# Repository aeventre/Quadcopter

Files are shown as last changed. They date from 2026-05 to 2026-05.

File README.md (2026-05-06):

# DIY Quadcopter

A from-scratch DIY quadcopter with a custom-designed flight computer PCB and custom frame CAD. Everything except the ESC and radio module was built from the ground up.
drone

## Overview

This repository contains the KiCad hardware design files for the custom flight controller PCB and the Arduino/PlatformIO firmware that runs on it. The flight controller interfaces a four channel off-the-shelf ESC, an RC receiver via CRSF/ExpressLRS, and an onboard 6-axis IMU to stabilize and control the drone.

## Hardware

### Flight Controller (Custom PCB)

| Component | Part | Role |
|---|---|---|
| MCU | Raspberry Pi Pico (RP2040 / RP2350) | Main processor |
| IMU | LSM6DSO32TR | 6-axis accelerometer + gyroscope (SPI) |
| Power regulator | TPS563200 | 3A synchronous step-down, 4.5–17V in → 3.3V |
| Motor switching | AO3400A MOSFET | N-channel switching |
| Level shifting | BSS138 MOSFET | 3.3V ↔ 5V logic |
| Transient protection | SMAJ14A TVS diode | Input voltage spike protection |

### Interfaces
- **4× ESC connectors** (Motor 1–4) — off-the-shelf 4 channel ESC
- **RC receiver connector** — CRSF/ExpressLRS
- **Electromagnet connector** — payload drop mechanism
- **SPI** — IMU (LSM6DSO32TR on SPI1)
- **USB** — programming and debug via Pico's onboard USB

### Frame & CAD
Custom-designed from scratch (CAD files not included in this repo).

## Firmware

Built with [PlatformIO](https://platformio.org/) targeting the Raspberry Pi Pico using the [earlephilhower Arduino core](https://github.com/earlephilhower/arduino-pico).

### Flight Controller (`Code/Controller_Code/`)

The main flight firmware. Initializes the IMU, ESCs, and CRSF receiver, then runs the control loop.

**Libraries (`lib/`)**

| Library | Description |
|---|---|
| `DroneController` | Core flight controller — PID loop, flight modes, arm/disarm, RAM blackbox |
| `ImuLSM6` | SPI driver for the LSM6DSO32TR (gyro + accel reads) |
| `MotorLib` | PWM motor control via the Servo library (1000–2000 µs) |

**Flight modes**

- **Acro** — pure rate mode; stick input maps directly to roll/pitch/yaw rate setpoints fed into the inner PID loop
- **Balance** — self-leveling; an outer angle P+I loop computes rate setpoints from stick-commanded angles, which the inner rate PID tracks

**Control loop**

```
RC input (CRSF)
    │
    ├─ [Balance mode] Angle P+I → rate setpoint
    │
    └─ Rate PID (roll / pitch / yaw)
           │   gyro LP filter (α = 0.70)
           │   complementary filter for attitude (α = 0.98)
           ▼
       Motor mixer → 4× PWM ESC outputs
```

**RAM blackbox**

Up to 3000 samples are logged to RAM during flight (timestamp, RC inputs, rate commands, gyro rates, PID outputs, motor values, attitude angles). On disarm the log dumps over USB serial as CSV for offline analysis.

### Test Projects

| Project | Description |
|---|---|
| `Code/ELRS_Test/` | Standalone CRSF/ExpressLRS receiver test |
| `Code/ESC_Test/` | ESC test using DShot600 (bit-banged on Pico's second core at 2 kHz) |
| `Code/IMU_test/` | Standalone LSM6DSO32TR read/print test |

### Flight Analysis (`Code/Flight_Analysis/`)

MATLAB script (`PID_Analysis.m`) for post-flight analysis of blackbox CSV logs. Plots RC inputs, commanded vs. measured rates, rate errors, motor outputs, and estimated attitude. 103 flight logs are included.

## Repository Structure

```
Quadcopter/
├── Flight_Controller/
│   ├── Flight_Controller.kicad_pro
│   ├── Flight_Controller.kicad_sch
│   └── Flight_Controller.kicad_pcb
└── Code/
    ├── Controller_Code/          # Main flight firmware (PlatformIO)
    │   ├── src/main.cpp
    │   ├── lib/
    │   │   ├── DroneController/  # Flight controller, PID, blackbox
    │   │   ├── ImuLSM6/          # LSM6DSO32TR SPI driver
    │   │   └── MotorLib/         # PWM ESC control
    │   └── Tests/                # Component test sketches
    ├── ELRS_Test/                # ExpressLRS receiver test
    ├── ESC_Test/                 # DShot600 ESC test
    │   └── lib/DshotLib/         # DShot600 driver (dual-core)
    ├── IMU_test/                 # IMU read test
    └── Flight_Analysis/
        ├── PID_Analysis.m        # MATLAB blackbox analysis script
        └── flight_log_*.csv      # Captured flight logs (103 flights)
```

## Getting Started

### Hardware (KiCad)
1. Install [KiCad 7.x or later](https://www.kicad.org/download/)
2. Clone this repository:
   ```bash
   git clone https://github.com/alecv2211/Quadcopter.git
   ```
3. Open `Flight_Controller/Flight_Controller.kicad_pro`

### Firmware (PlatformIO)
1. Install [PlatformIO](https://platformio.org/install)
2. Open `Code/Controller_Code/` in VS Code with the PlatformIO extension
3. Connect the Pico via USB and run **Upload**

## License

Licensed under the [Apache License 2.0](LICENSE).

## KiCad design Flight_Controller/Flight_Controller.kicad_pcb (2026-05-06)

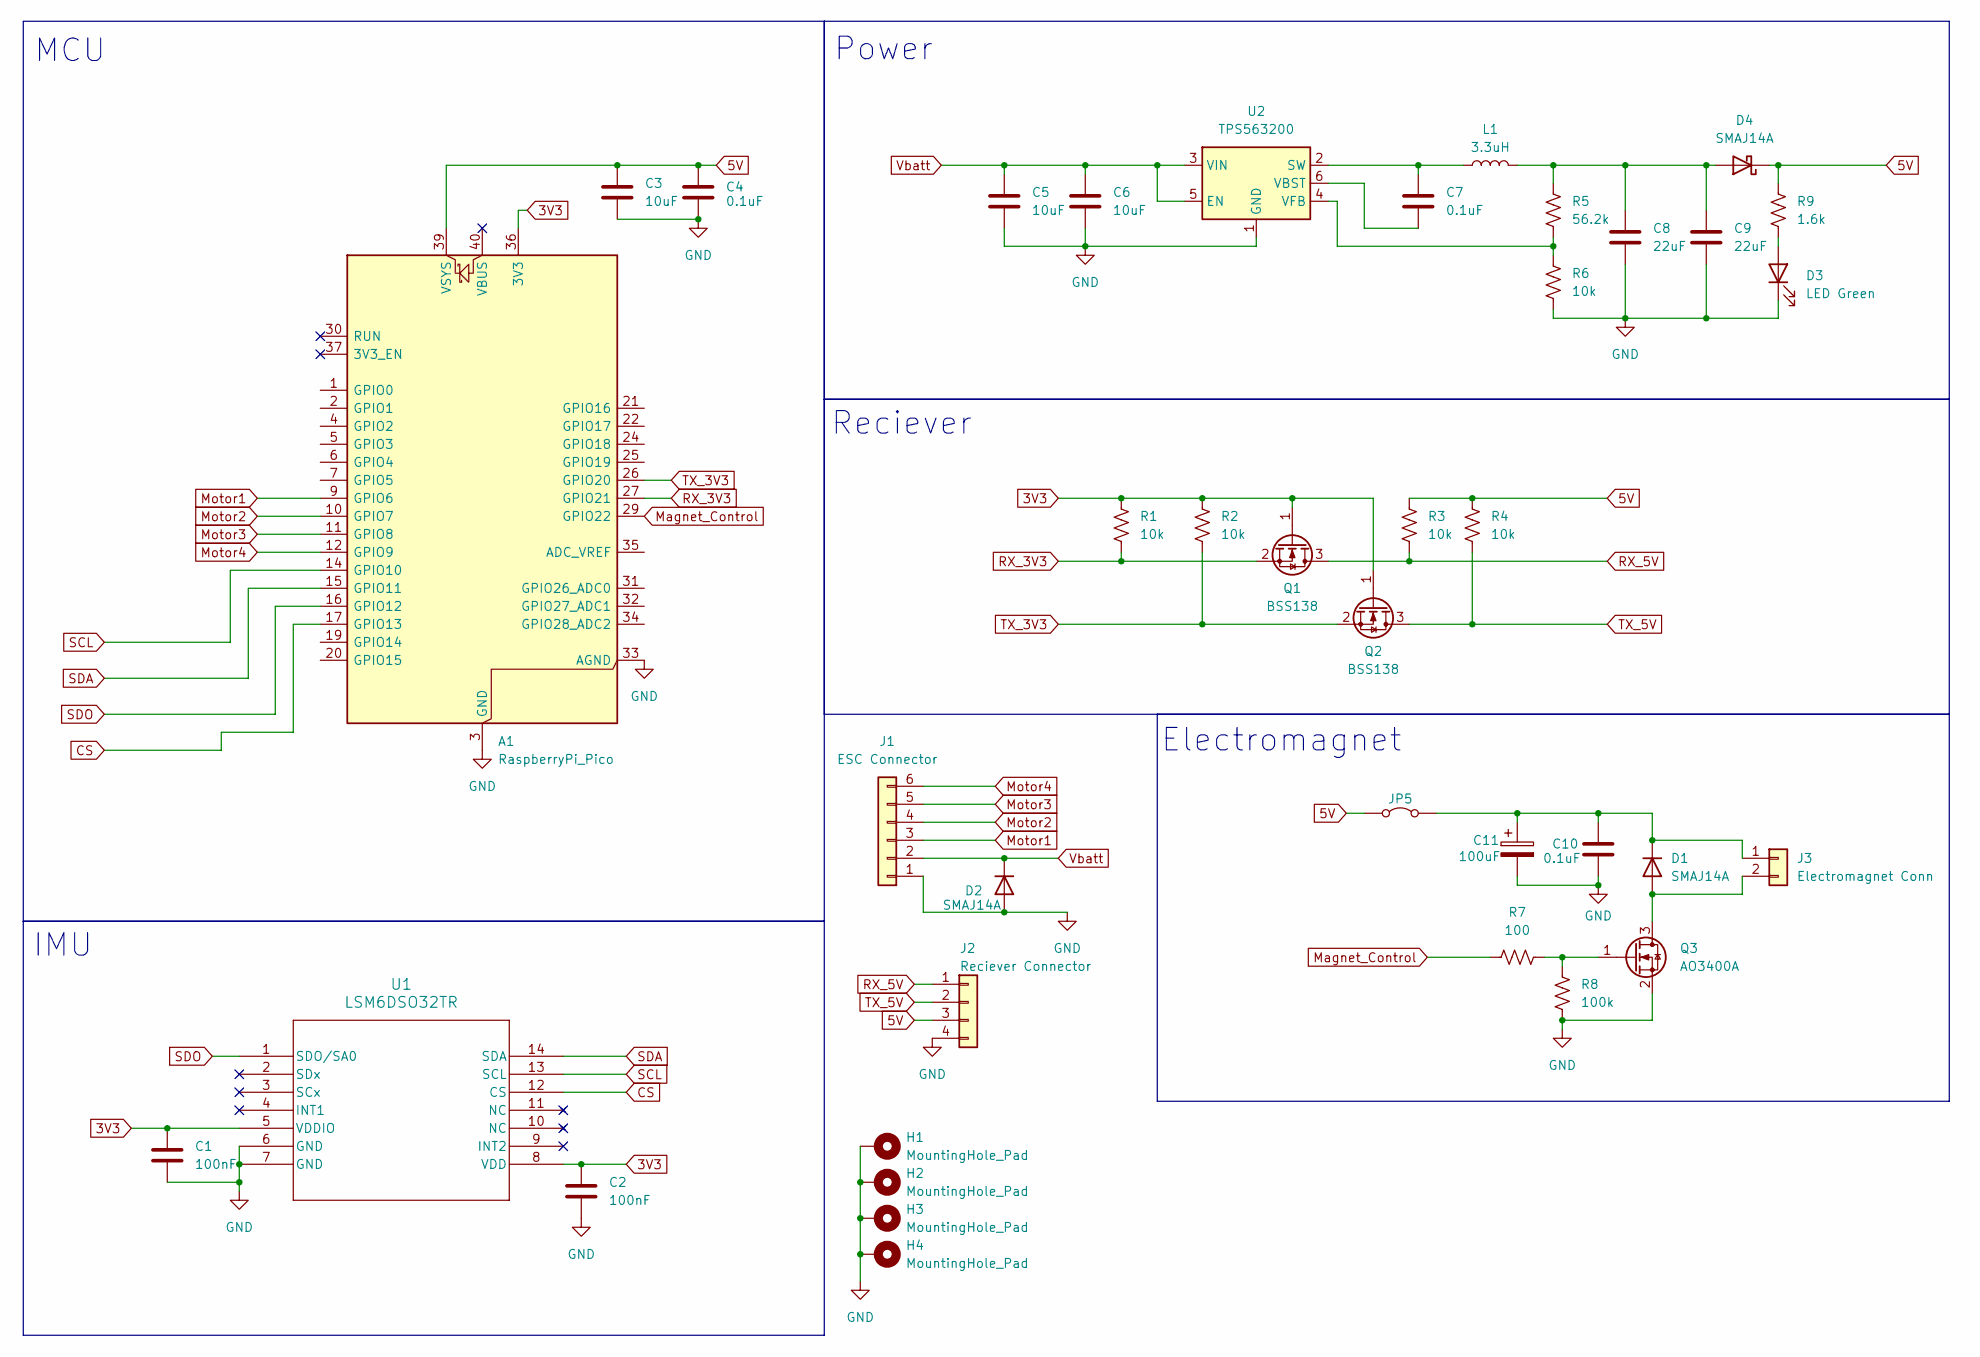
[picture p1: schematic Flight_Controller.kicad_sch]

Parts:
A1: RaspberryPi_Pico; RaspberryPi_Pico_Common_SMD
C1, C2: 100nF; C_0603_1608Metric_Pad1.08x0.95mm_HandSolder
C3: 10uF; C_0603_1608Metric_Pad1.08x0.95mm_HandSolder; Digikey Part Number 399-C0805C106K4PACTUCT-ND
C4: 0.1uF; C_0603_1608Metric_Pad1.08x0.95mm_HandSolder; Digikey Part Number 399-C0805C104M5UACTUCT-ND
C5, C6: 10uF; C_0603_1608Metric_Pad1.08x0.95mm_HandSolder
C7, C10: 0.1uF; C_0603_1608Metric_Pad1.08x0.95mm_HandSolder
C8, C9: 22uF; C_0603_1608Metric_Pad1.08x0.95mm_HandSolder
C11: 100uF; C_0603_1608Metric_Pad1.08x0.95mm_HandSolder
D1, D2, D4: SMAJ14A; D_SMA_Handsoldering
D3: LED Green; D_0603_1608Metric_Pad1.05x0.95mm_HandSolder
H1, H2, H3, H4: MountingHole_Pad; MountingHole_3.5mm_Pad
J1: ESC Connector; SolderWire-0.15sqmm_1x06_P4mm_D0.5mm_OD1.5mm_Relief
J2: Reciever Connector; Reciever_Module
J3: Electromagnet Conn; SolderWire-0.15sqmm_1x02_P4mm_D0.5mm_OD1.5mm_Relief
JP5: Jumper_2_Bridged; SolderJumper-2_P1.3mm_Open_TrianglePad1.0x1.5mm
L1: 3.3uH; L_Bourns-SRN8040_8x8.15mm
Q1, Q2: BSS138; SOT-23_Handsoldering
Q3: AO3400A; SOT-23
R1, R2, R3, R4: 10k; R_0603_1608Metric_Pad0.98x0.95mm_HandSolder; PART-NUMBER CPF0603F10KC1
R5: 56.2k; R_0603_1608Metric_Pad0.98x0.95mm_HandSolder
R6: 10k; R_0603_1608Metric_Pad0.98x0.95mm_HandSolder
R7: 100; R_0603_1608Metric_Pad0.98x0.95mm_HandSolder; PART-NUMBER CPF0603F10KC1
R8: 100k; R_0603_1608Metric_Pad0.98x0.95mm_HandSolder; PART-NUMBER CPF0603F10KC1
R9: 1.6k; R_0603_1608Metric_Pad0.98x0.95mm_HandSolder
U1: LSM6DSO32TR; LGA-14_3x2.5mm_P0.5mm_LayoutBorder3x4y; PART-NUMBER 497-LSM6DSO32CT-ND
U2: TPS563200; SOT-23-6

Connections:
3V3: A1.36 (3V3), C1.1, C2.1, Q1.1 (G), Q2.1 (G), R1.1, R2.1, U1.5 (VDDIO), U1.8 (VDD)
5V: A1.39 (VSYS), C3.1, C4.1, D4.1 (K), J2.3, JP5.1 (A), R3.1, R4.1, R9.1
CS: A1.17 (GPIO13), U1.12 (CS)
GND: A1.3 (GND), A1.8 (GND), A1.13 (GND), A1.18 (GND), A1.23 (GND), A1.28 (GND), A1.33 (AGND), A1.38 (GND), C1.2, C2.2, C3.2, C4.2, C5.2, C6.2, C8.2, C9.2, C10.2, C11.2, D2.2 (A), D3.1 (K), H1.1, H2.1, H3.1, H4.1, J1.1, J2.4, Q3.2 (S), R6.2, R8.1, U1.6 (GND), U1.7 (GND), U2.1 (GND)
Magnet_Control: A1.29 (GPIO22), R7.1
Motor1: A1.9 (GPIO6), J1.3
Motor2: A1.10 (GPIO7), J1.4
Motor3: A1.11 (GPIO8), J1.5
Motor4: A1.12 (GPIO9), J1.6
unnamed: D1.2 (A), J3.2, Q3.3 (D)
unnamed: C10.1, C11.1, D1.1 (K), J3.1, JP5.2 (B)
unnamed: D3.2 (A), R9.2
unnamed: C8.1, C9.1, D4.2 (A), L1.2, R5.1
unnamed: Q3.1 (G), R7.2, R8.2
unnamed: C7.1, L1.1, U2.2 (SW)
unnamed: C7.2, U2.6 (VBST)
unnamed: R5.2, R6.1, U2.4 (VFB)
RX_3V3: A1.27 (GPIO21), Q1.2 (S), R1.2
RX_5V: J2.1, Q1.3 (D), R3.2
SCL: A1.14 (GPIO10), U1.13 (SCL)
SDA: A1.15 (GPIO11), U1.14 (SDA)
SDO: A1.16 (GPIO12), U1.1 (SDO/SA0)
TX_3V3: A1.26 (GPIO20), Q2.2 (S), R2.2
TX_5V: J2.2, Q2.3 (D), R4.2
Vbatt: C5.1, C6.1, D2.1 (K), J1.2, U2.3 (VIN), U2.5 (EN)

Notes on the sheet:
MCU
IMU
Power
Reciever
Electromagnet

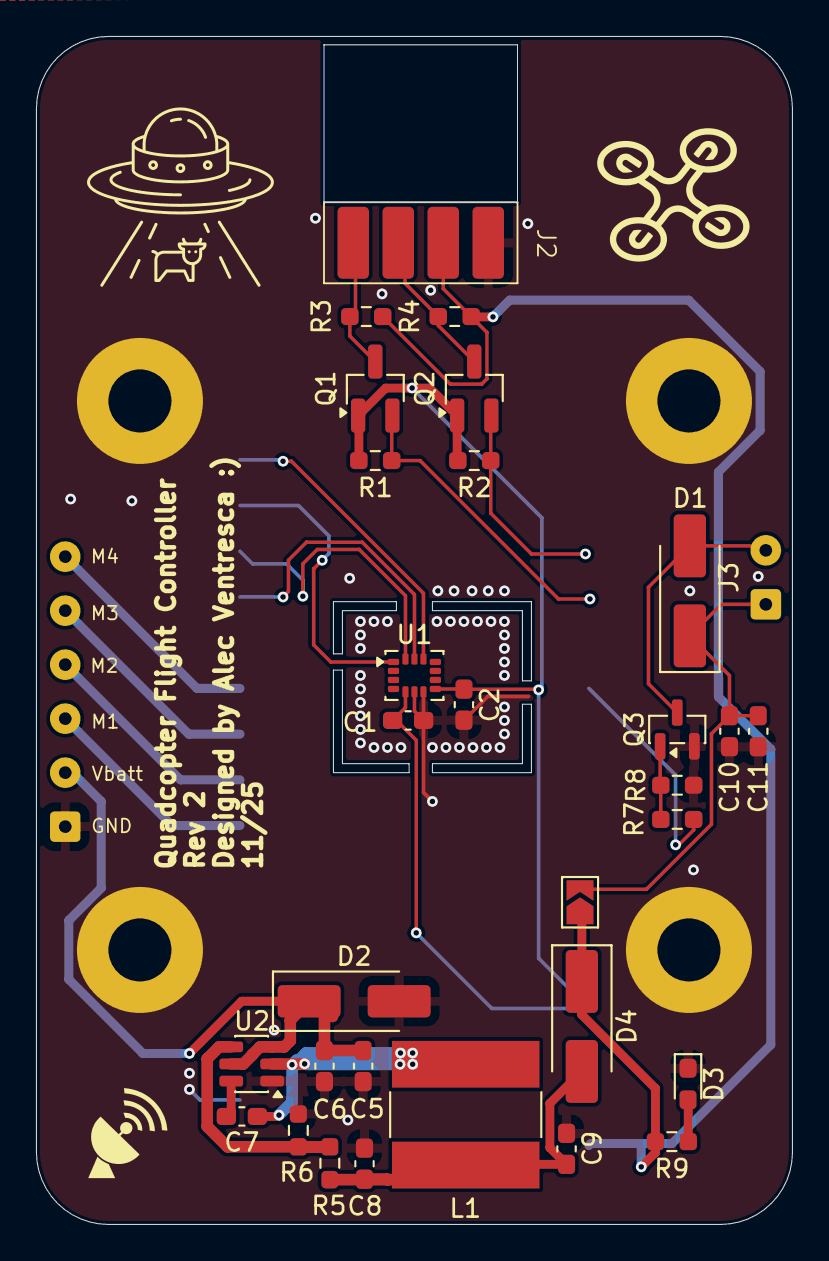
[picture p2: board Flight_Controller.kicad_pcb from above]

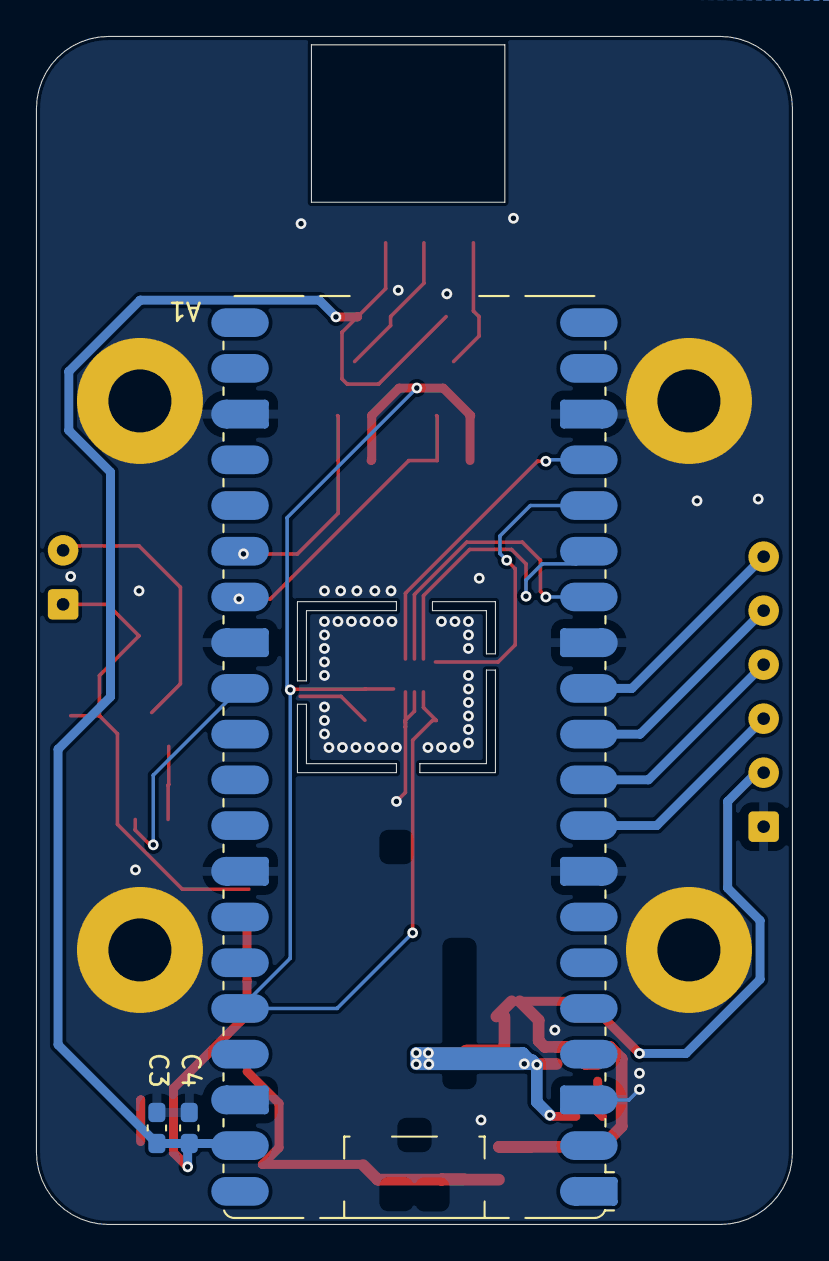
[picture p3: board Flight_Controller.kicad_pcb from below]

Board: 2 copper layers, 42.0 x 66.0 mm, 39 parts (3 on the bottom side), 25 nets.

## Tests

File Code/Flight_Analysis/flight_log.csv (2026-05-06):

Channel 1 | Channel 2 | Channel 3 | Channel 4 | Channel 5 | Channel 6 | Channel 7 | Channel 8 | Channel 9 | Channel 10 | Channel 11 | Channel 12 | Channel 13 | Channel 14 | Channel 15 | Channel 16 | Channel 17 | Channel 18 | Channel 19 | Channel 20
5198876.000000 | 1500.000000 | 1500.000000 | 993.000000 | 1482.000000 | 0.000000 | 0.000000 | -4.300000 | 0.000000 | 0.000000 | 0.000000 | 0.000000 | 0.000000 | -3.900000 | 0.000000 | 3.000000 | 3.000000 | 0.000000 | 0.200000 | -1.000000
5201606.000000 | 1500.000000 | 1500.000000 | 993.000000 | 1482.000000 | 0.000000 | 0.000000 | -4.300000 | 0.000000 | 0.000000 | 0.000000 | 0.000000 | 0.000000 | -3.200000 | 0.000000 | 2.000000 | 2.000000 | 0.000000 | 0.200000 | -1.000000
5203886.000000 | 1500.000000 | 1500.000000 | 993.000000 | 1482.000000 | 0.000000 | 0.000000 | -4.300000 | 0.000000 | 0.000000 | 0.000000 | 0.000000 | 0.000000 | -3.900000 | 0.000000 | 3.000000 | 3.000000 | 0.000000 | 0.200000 | -1.000000
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

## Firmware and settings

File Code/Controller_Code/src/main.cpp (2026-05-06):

#include <Arduino.h>
#include <SPI.h>

#include "CRSFforArduino.hpp"
#include "DroneController.h"
#include "ImuLSM6.h"
#include "MotorLib.h"

// ======================= Motor / ESC setup =======================
uint8_t motorPins[4] = {6, 7, 8, 9};
MotorController motors(1000, 2000); // 1000–2000 us

// ======================= IMU object =======================
static const uint8_t IMU_CS_PIN = 13;
ImuLSM6 imu(SPI1, IMU_CS_PIN);

// ======================= CRSF / ELRS =======================
CRSFforArduino *crsf = nullptr;

// ======================= Controller =======================
DroneController drone(motors, imu);

// Forward declaration for CRSF callback
void onReceiveRcChannels(serialReceiverLayer::rcChannels_t *rcChannels);

void setup()
{
    Serial.begin(115200);
    while (!Serial && millis() < 2000)
    {
    }
    pinMode(22, OUTPUT);
    digitalWrite(22, LOW);

    Serial.println("=== Drone main (rate + angle outer loop + RAM blackbox) ===");

    // ---- ESC init ----
    motors.begin(motorPins, 4);
    Serial.println("ESC init: sending 1000us (0% throttle) for 3s...");
    motors.setAllThrottle(0.0f); // -> 1000us
    delay(3000);

    // ---- IMU SPI init ----
    SPI1.setSCK(10); // SCK
    SPI1.setTX(11);  // MOSI
    SPI1.setRX(12);  // MISO
    SPI1.begin();

    imu.begin();
    Serial.println("IMU init done.");

    // ---- CRSF / ELRS init ----
    Serial2.setRX(21);
    Serial2.setTX(20);

    crsf = new CRSFforArduino(&Serial2);
    if (!crsf)
    {
        Serial.println("[ERROR] Failed to allocate CRSF");
        while (1)
        {
            delay(1000);
        }
    }

    if (!crsf->begin())
    {
        Serial.println("[ERROR] crsf->begin() FAILED");
        while (1)
        {
            delay(1000);
        }
    }

    drone.setCrsf(crsf);

    // RC callback forwards into DroneController
    crsf->setRcChannelsCallback(onReceiveRcChannels);

    Serial.println("Setup complete. Waiting for RC frames...");
}

void loop()
{
    drone.update();
}

// RC callback just forwards into DroneController
void onReceiveRcChannels(serialReceiverLayer::rcChannels_t *rcChannels)
{
    drone.handleRcUpdate(*rcChannels);
}

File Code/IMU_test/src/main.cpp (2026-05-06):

#include <Arduino.h>
#include <SPI.h>

// ==== Pin + register defs ====
#define CS_PIN    13      // GPIO13 → IMU CS

// LSM6DSO32 registers
#define WHO_AM_I  0x0F
#define CTRL1_XL  0x10
#define CTRL2_G   0x11
#define CTRL3_C   0x12
#define OUTX_L_G  0x22    // start of gyro data (6 bytes)
#define OUTX_L_A  0x28    // start of accel data (6 bytes)

// Expected WHO_AM_I value
#define WHO_VAL   0x6C

// ---- Sensitivities ----
// Treat accel as ±2g for scaling:
// ±2g : 0.061 mg/LSB → 0.000061 g/LSB
const float ACC_SENS = 0.000244f;    // g/LSB

// Gyro: ±250 dps → 8.75 mdps/LSB → 0.00875 dps/LSB
const float GYRO_SENS_250 = 0.00875f;    // dps/LSB

// One SPI config for all IMU transactions
SPISettings imuSPI(1000000, MSBFIRST, SPI_MODE3);

// ==== Low-level SPI helpers ====
uint8_t imuReadReg(uint8_t reg)
{
  uint8_t v;

  digitalWrite(CS_PIN, LOW);
  SPI1.beginTransaction(imuSPI);
  SPI1.transfer(reg | 0x80);   // MSB=1 → read
  v = SPI1.transfer(0x00);
  SPI1.endTransaction();
  digitalWrite(CS_PIN, HIGH);

  return v;
}

void imuWriteReg(uint8_t reg, uint8_t val)
{
  digitalWrite(CS_PIN, LOW);
  SPI1.beginTransaction(imuSPI);
  SPI1.transfer(reg & 0x7F);   // MSB=0 → write
  SPI1.transfer(val);
  SPI1.endTransaction();
  digitalWrite(CS_PIN, HIGH);
}

// ==== High-level IMU helpers ====

// Burst-read gyro + accel in one go (12 bytes)
void imuReadGyroAccel(float &gx, float &gy, float &gz,
                      float &ax, float &ay, float &az)
{
  uint8_t buf[12];

  digitalWrite(CS_PIN, LOW);
  SPI1.beginTransaction(imuSPI);
  // Start at OUTX_L_G, auto-increment will step through all 6 gyro + 6 accel bytes
  SPI1.transfer(OUTX_L_G | 0x80);

  for (int i = 0; i < 12; i++) {
    buf[i] = SPI1.transfer(0x00);
  }

  SPI1.endTransaction();
  digitalWrite(CS_PIN, HIGH);

  // Raw little-endian 16-bit values
  int16_t gx_raw = (int16_t)((buf[1]  << 8) | buf[0]);
  int16_t gy_raw = (int16_t)((buf[3]  << 8) | buf[2]);
  int16_t gz_raw = (int16_t)((buf[5]  << 8) | buf[4]);
  int16_t ax_raw = (int16_t)((buf[7]  << 8) | buf[6]);
  int16_t ay_raw = (int16_t)((buf[9]  << 8) | buf[8]);
  int16_t az_raw = (int16_t)((buf[11] << 8) | buf[10]);

  // Convert to physical units
  gx = gx_raw * GYRO_SENS_250;
  gy = gy_raw * GYRO_SENS_250;
  gz = gz_raw * GYRO_SENS_250;

  ax = ax_raw * ACC_SENS;
  ay = ay_raw * ACC_SENS;
  az = az_raw * ACC_SENS;
}

void imuInit()
{
  // CTRL3_C: BDU=1 (block data update), IF_INC=1 (auto-increment)
  // 0b0100_0100 = 0x44
  imuWriteReg(CTRL3_C, 0x44);
  delay(50);   // give it a moment to latch

  // CTRL1_XL: ODR_XL = 104 Hz (0100 << 4 = 0x40)
  // We'll *ask* for ±4g (0x48), but even if FS bits don't stick,
  // our scale constant is now based on what we actually observe.
  imuWriteReg(CTRL1_XL, 0x48);

  // CTRL2_G (gyro):
  // ODR_G  = 104 Hz → 0b0100 << 4 = 0x40
  // FS_G   = 250 dps (00 in bits [3:2])
  // Final: 0x40
  imuWriteReg(CTRL2_G, 0x40);

  delay(20);

  // Read back to confirm (for debugging / curiosity)
  uint8_t c1 = imuReadReg(CTRL1_XL);
  uint8_t c2 = imuReadReg(CTRL2_G);
  uint8_t c3 = imuReadReg(CTRL3_C);

  Serial.print("CTRL1_XL = 0x"); Serial.println(c1, HEX);
  Serial.print("CTRL2_G  = 0x"); Serial.println(c2, HEX);
  Serial.print("CTRL3_C  = 0x"); Serial.println(c3, HEX);
}

void setup()
{
  Serial.begin(115200);
  delay(2000);

  Serial.println("\n=== LSM6DSO32 SPI Gyro+Accel Test (2g scaling) ===");

  // Configure SPI1 pins to match your PCB routing
  SPI1.setSCK(10);   // GPIO10 → SCK
  SPI1.setTX(11);    // GPIO11 → MOSI
  SPI1.setRX(12);    // GPIO12 → MISO
  SPI1.begin();

  pinMode(CS_PIN, OUTPUT);
  digitalWrite(CS_PIN, HIGH);

  // WHO_AM_I sanity check
  uint8_t who = imuReadReg(WHO_AM_I);
  Serial.print("WHO_AM_I = 0x");
  Serial.println(who, HEX);

  if (who != WHO_VAL) {
    Serial.println("WARNING: IMU WHO_AM_I mismatch (expected 0x6C).");
  }

  imuInit();
  Serial.println("IMU init done (scaled as ±2g, ±250 dps @ 104 Hz).");
}

void loop()
{
  float gx, gy, gz;
  float ax, ay, az;

  imuReadGyroAccel(gx, gy, gz, ax, ay, az);

  Serial.print("ACC [g]   ");
  Serial.print(ax, 3); Serial.print("   ");
  Serial.print(ay, 3); Serial.print("   ");
  Serial.print(az, 3); Serial.print("   |   ");

  Serial.print("GYR [dps] ");
  Serial.print(gx, 2); Serial.print("   ");
  Serial.print(gy, 2); Serial.print("   ");
  Serial.print(gz, 2); Serial.println();

  

  delay(50);   // ~20 Hz print
}

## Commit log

2025-11-01 Prepared sheets for each component
    [Control_Board.kicad_pcb, Control_Board.kicad_sch, controller.kicad_sch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]
2025-11-01 Change folder name
    [Control_Board.kicad_pcb, Control_Board.kicad_sch, controller.kicad_sch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]
2025-11-02 add stm32
    [Flight_Controller.kicad_pcb, Flight_Controller.kicad_sch, controller.kicad_sch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]
2025-11-21 Rev 2 PCB done
    [Flight_Controller.kicad_pcb, Flight_Controller.kicad_sch, controller.kicad_sch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]
2026-05-06 Update README with hardware details from schematic
2026-05-06 Add firmware source, test projects, flight analysis data, and update .gitignore
    [flight_log.csv, flight_log_10.csv, flight_log_100.csv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]
